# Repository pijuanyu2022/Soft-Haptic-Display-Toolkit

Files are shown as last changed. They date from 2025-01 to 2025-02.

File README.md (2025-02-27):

# Soft Haptic Display (SHD) Toolkit



A **fingertip-sized, high-resolution pneumatic haptic display** designed to provide realistic tactile feedback in virtual reality (VR) environments or during robot teleoperation. This repository includes all the **hardware** (CAD files, BOM) and **software** (Arduino, Raspberry Pi, GUI) needed to build and control the SHD.

---

## Table of Contents

- [Features](#features)
- [Screenshots](#screenshots)
- [Project Structure](#project-structure)

- [Installation](#installation)
- [Quick Start](#quick-start)
- [Documentation](#documentation)
- [Contributing](#contributing)
- [License](#license)
- [Citation & References](#citation--references)
- [Acknowledgments](#acknowledgments)

---

## Features

- **4×4 Wearable Tactile Array** – A low-cost silicone actuator array with 16 individually controlled chambers.
- **Desktop-Sized Control Box** – Integrates an Arduino Due, a Raspberry Pi, and pneumatic valves.
- **Real-Time Control** – Low-latency wireless communication between the SHD and a PC or VR platform.
- **Open-Source** – All code, CAD files, and documentation are released under the MIT license.
- **Easy to Build** – Minimal development time; accessible to students and researchers with diverse backgrounds.

---

## Screenshots

The **4 × 4 tactile array haptic display (red)** is connected to the **control box (white)** via transparent air tubes. The control box communicates with the laptop **wirelessly** using a socket communication method.

<p>
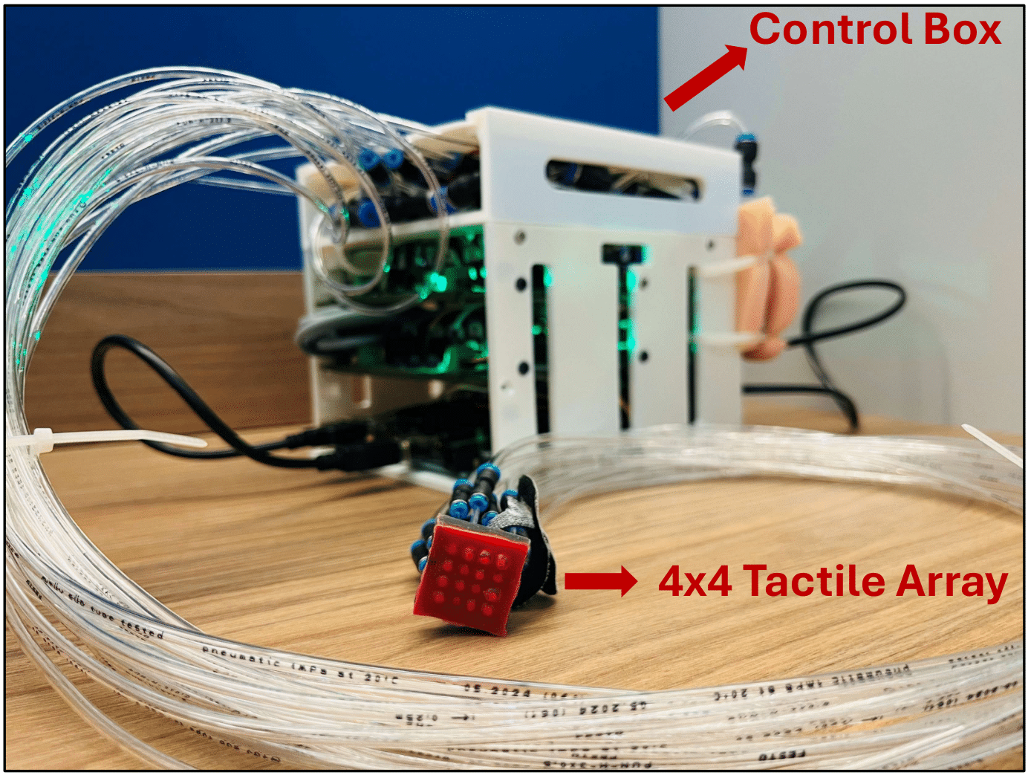
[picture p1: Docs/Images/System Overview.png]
static animation 1
  
  
</p>

**Selected Static Patterns**
<p>
  static animation 1
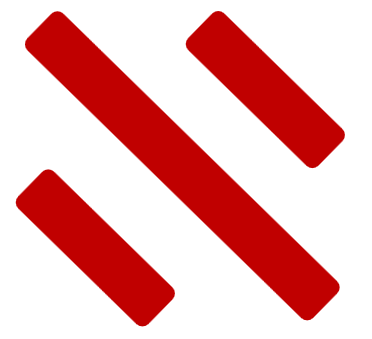
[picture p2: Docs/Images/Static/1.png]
static 1
  
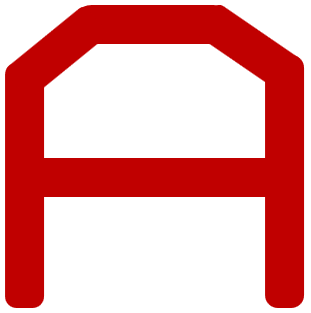
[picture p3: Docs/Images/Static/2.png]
static 2
  
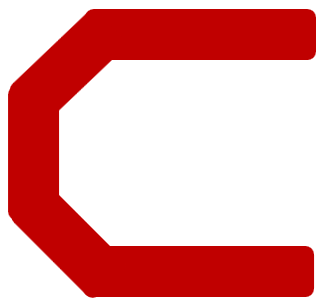
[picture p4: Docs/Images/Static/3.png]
static 3
  
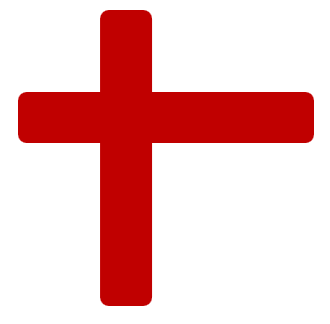
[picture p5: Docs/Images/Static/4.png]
static 4
  
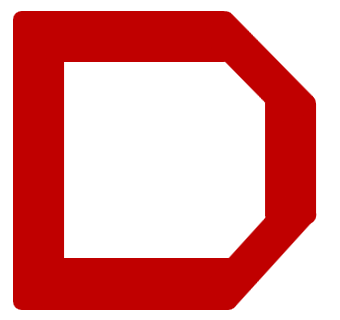
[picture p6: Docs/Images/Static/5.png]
static 5
  
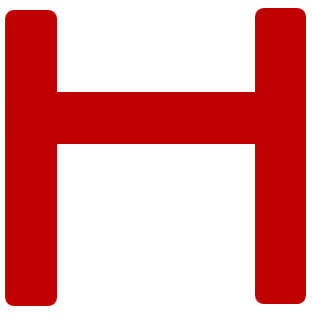
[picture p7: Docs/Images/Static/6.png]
static 6
  
  
</p>

**Selected Animation Patterns**
<p>
  Animation gif 1
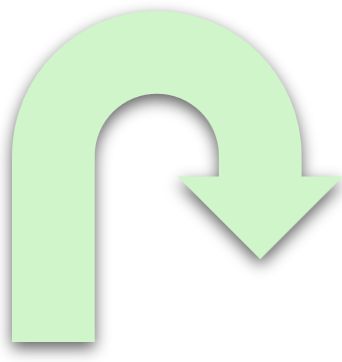
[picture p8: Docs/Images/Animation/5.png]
Animation 1
  
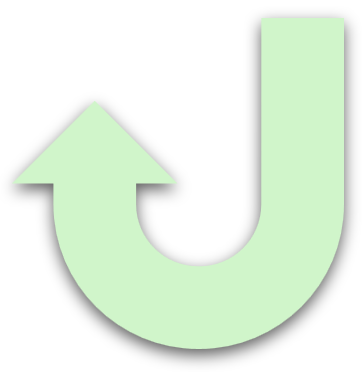
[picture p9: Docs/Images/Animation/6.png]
Animation 2
  
</p>

<p>
  Animation gif 2
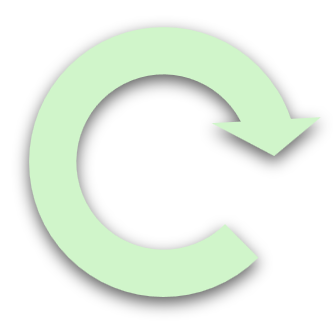
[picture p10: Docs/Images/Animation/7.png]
Animation 3
  
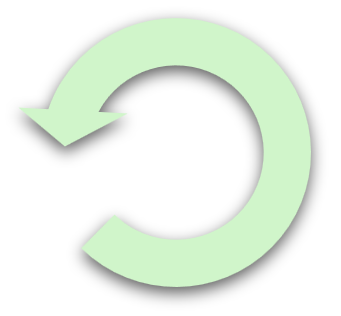
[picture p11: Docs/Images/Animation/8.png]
Animation 4
  
  
</p>

<p>
  Animation gif 3
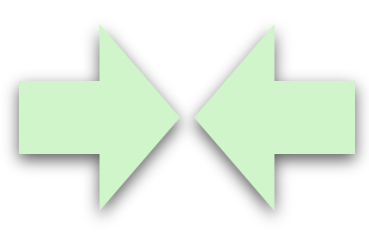
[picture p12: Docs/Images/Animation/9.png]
Animation 5
  
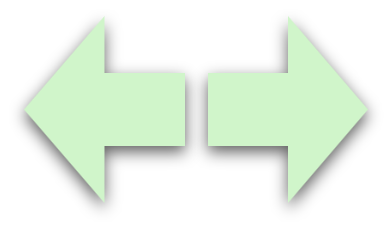
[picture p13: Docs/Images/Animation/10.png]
Animation 6
  
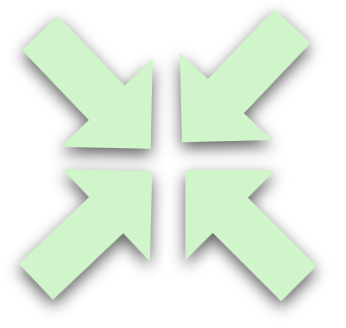
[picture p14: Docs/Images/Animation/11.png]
Animation 7
  
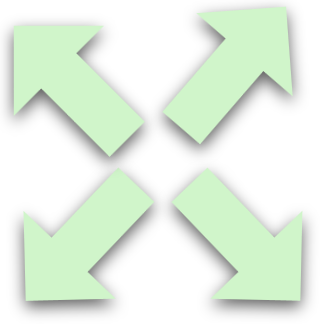
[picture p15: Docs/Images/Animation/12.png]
Animation 8
  
  
</p>

---

## Project Structure

Here’s an overview of how this repository is organized:

```plaintext
Soft-haptic-display/
├── hardware/
│   ├── CAD/           # 3D/2D design files (STLs, STEP, source CAD)
│   ├── schematics/    # Electronics circuit diagrams
│   ├── BOM/           # Bill of Materials (CSV or Markdown)
├── firmware/
│   ├── arduino/       # Arduino sketches for low-level control
│   └── raspberry_pi/  # Scripts running on the Pi
├── software/
│   └── gui/           # GUI code on the Computer for controlling the SHD
├── docs/
│   ├── manual/        # User manual, assembly guide
│   ├── images/        # Animation pictures, Gif, Static pictures
├── LICENSE
├── README.md
└── CONTRIBUTING.md

```
--- 

## Installation

### Hardware Assembly

Purchase all required items from:
- [list of Controller.md](Hardware/Bill%20of%20Materials/list%20of%20Controller.md)
- [list of Pneumatic.md](Hardware/Bill%20of%20Materials/list%20of%20Pneumatic.md)
- [list of Silicone.md](Hardware/Bill%20of%20Materials/list%20of%20Silicone.md)

Follow the instructions in [Docs/Manual/Hardware_tutorial.md](Docs/Manual/Hardware_tutorial.md) to:
1. **3D-print** the mold and control box.
2. **Fabricate** the tactile array.
3. **Solder** the control board.
4. **Assemble** the entire control box and connect it to the tactile array.

---
### Install Software on Your Windows PC

1. **Fork** this repository in GitHub.
2. **Open GitHub Desktop** and clone your fork to your local machine.
3. **Open the cloned repository** in Visual Studio Code or any other Python IDE.
4. **Locate** the `main.py` file in the `soft-haptic-display-toolkit/Software` directory:
   ```plaintext
   python main.py
   ```
5. Install all required Python libraries until the GUI successfully appears on your computer.

---
### Install Software on the Raspberry Pi

1. **Connect** the Raspberry Pi to a monitor.
2. **Open a terminal** on the Raspberry Pi:
```plaintext
git clone https://github.com/pijuanyu2022/Soft-Haptic-Display-Toolkit.git
cd Soft-Haptic-Display-Toolkit/Firmware/Raspberry_Pi/
```
3. **Create a virtual environment** in the terminal window:
```plaintext
python -m venv SoftRobo
source SoftRobo/bin/activate
```

4. **Install**  all required Python libraries so that `run_robot.py` can be opened correctly:
```plaintext
python run_robot.py
```

---
### Install Software on the Arduino Uno

1. **Connect** the Arduino Uno to your PC.
2. **Navigate** to the `/Firmware/Arduino/` directory and open `Pneumatic.ino` in the Arduino IDE.
3. **Select** Arduino Uno under *Tools → Board* in the Arduino IDE.
4. **Upload** the code to the Arduino Uno.

Tips: You can also install the Arduino IDE on the Raspberry Pi and use the Pi to upload the code to the Arduino Uno.

---
## Quick Start

#### Step 1. **Connect your PC and Raspberry Pi** to the same Wi-Fi network.

#### Step 2. **Find the Raspberry Pi’s IP address**:
- On the Raspberry Pi’s **Terminal**, type:
```plaintext
ifconfig
```
- Look for the `wlan0` or `eth0` section. The IP might look like `192.168.x.x`.

#### Step 3. **Open a Command Prompt** on your Windows PC:
- Press the **Start Menu** or **Taskbar** search, type `"cmd"`, and press Enter.

#### Step 4. Click Command Prompt and put
```plaintext
ssh [username]@[IP address]
```
- Example
```plaintext
ssh pi@192.168.1.100
```
- Enter the Pi’s password when prompted.

#### Step 5. Once connected, you should see something like:
```plaintext
pi@raspberrypi: ~ $
```
This indicates that the Command Prompt is now logged into your Raspberry Pi.

#### Step 6. Start the control script on the Pi:
```plaintext
cd Soft-Haptic-Display-Toolkit/Firmware/Raspberry_Pi/
source SoftRobo/bin/activate
python run_robot.py
```
- Keep this Command Prompt session open so the script keeps running.

#### Step 7. On your Windows PC, open Visual Studio Code (or another Python IDE):
- Navigate to the cloned repository folder:
```plaintext
Soft-Haptic-Display-Toolkit/Software
```
- Locate and **run** `main.py`.

#### Step 8. In the GUI that appears, **click the `Connect` button** (top-left corner) and **enter the Raspberry Pi’s IP address** (the same one used for SSH).

#### Step 9. **Follow** the [GUI_tutorial.md](Docs/Manual/GUI_tutorial.md) for detailed steps on controlling the tactile display.
- You should now be able to **inflate** and **deflate** the soft haptic array channels in real time!

---
## Documentation
- Assembly & Fabrication: [docs/manual/Hardware_tutorial.md](Docs/Manual/Hardware_tutorial.md)
- Firmware Guides: [docs/manual/Firmware_tutorial.md](Docs/Manual/Firmware_tutorial.md)
- GUI Usage: [docs/manual/GUI_tutorial.md](Docs/Manual/GUI_tutorial.md)
- Troubleshooting: [docs/Troubleshooting.md](Docs/troubleshooting.md)
- Bill of controller: [Hardware/Bill of Materials/list of Controller.md](Hardware/Bill%20of%20Materials/list%20of%20Controller.md)
- Bill of pneumatic system: [Hardware/Bill of Materials/list of Pneumatic.md](Hardware/Bill%20of%20Materials/list%20of%20Pneumatic.md)
- Bill of tactile dislay: [Hardware/Bill of Materials/list of Silicone.md](Hardware/Bill%20of%20Materials/list%20of%20Silicone.md)

For any **unresolved issues**, please file a ticket under the Issues tab.

---
## Contributing
We welcome all forms of contributions—bug reports, feature requests, code improvements, and documentation updates. To get started:
1. **Fork** this repository.
2. **Create** a new branch (e.g., feature/new-valve-driver).
3. **Commit** and **push** your changes.
4. **Open** a Pull Request describing your modifications.

---
## License
This project is licensed under the terms of the [MIT License](./LICENSE).

You are free to **use, modify, and distribute** this work as long as you include the original license and attribution to the authors.

---
## Citation & References
We are planning to submit this research to the 2025 Ubiquitous Robots Conference as a regular paper. The citation will be listed in the future.

---
## Acknowledgments
Special thanks to our collaborators and the open-source community:
- Our [Friesen Haptics Lab](https://www.friesenhaptics.com/.).
- The [INVENT Lab](https://www.theinventlab.com/).
- The [Human Factors & Cognitive Systems (HF&CS) Lab](https://tamuhfeschapter.wordpress.com/labs/human-factors-cognitive-systems-hfcs-lab/).
- The [Soft Robotics Toolkit](https://softroboticstoolkit.com/) for inspiration and design references.
- The [Soft Robotics Control-unit (SRC)](https://github.com/chukhanhhoang/SoftRoboticSetupFesto?tab=readme-ov-file) for control references.

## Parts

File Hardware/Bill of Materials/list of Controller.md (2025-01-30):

| **Item** | **Description** | **Quantity** | **Supplier** | **Part Number** | **Approx. Cost (USD)** |
|---|---|---:|---|---|---:|
| Raspberry Pi 5 | SBC 2.4GHZ 4 CORE 8GB RAM | 1 | Digikey | [2648-SC1112-ND](https://www.digikey.com/en/products/detail/raspberry-pi/SC1112/21658257?src=raspberrypi) | $ 80 
| Arduino Uno REV3 | Microcontroller | 1 | Arduino | [Link to Amazon](https://www.amazon.com/dp/B008GRTSV6?ref=fed_asin_title&th=1) | $ 23.50
| ACTIVE COOLER | Cooler for Raspberry Pi 5 | 1 | Digikey | [2648-SC1148-ND](https://www.digikey.com/en/products/detail/raspberry-pi/SC1148/21658255) | $ 5.00
| Pressure Regulator | 3-way proportional pressure control valve | 1 | Festo | [2171-VEAB-L-26-D13-Q4-V1-1R1-ND](https://www.festo.com/us/en/a/8067677/?autoShowCad=true) | $ 754.08 |
| Pressure Regulator Cable | Festo pressure regulator connecting cable | 1| Festo | [NEBA-M8W4-U-2.5-N-LE4](https://www.festo.com/us/en/a/8078233/) | $ 16.73
| VEAB board | Control the pressure regulator | 1 | jclPCB| [Link to jclPCB Part](https://github.com/chukhanhhoang/SoftRoboticSetupFesto/blob/main/hardware/Hardware.md)  | \$ 14.20 |
| PCA9548 | 8-Channel STEMMA QT / Qwiic I2C Multiplexer | 1 | Adafruit | [5626](https://www.adafruit.com/product/5626) | $ 5.00
| Pressure sensor | MPRLS Ported Pressure Sensor | 8 | Adafruit | [3965](https://www.adafruit.com/product/3965) | $ 29.95 each
| Air Mini Valve | 6V Air Valve with 2-pin JST XH Connector | 16 | Adafruit | [4663](https://www.adafruit.com/product/4663) | $ 2.95 each
| Air Mini Pump | Air Pump and Vacuum DC Motor - 4.5 V and 2.5 LPM | 1| Adafruit | [4699](https://www.adafruit.com/product/4699) | $ 7.95
| TIP120 Transistors | TIP120 Power Darlington Transistors - 3 pack | 20 | Adafruit | [976](https://www.adafruit.com/product/976) | $ 2.50 each
| 1N4001 Diode | 10 pack of the classic 1N4001 power blocking diode | 2 | Adafruit | [755](https://www.adafruit.com/product/755) | $ 1.50 each
| 12 V to 6V converter | DROK 12V to 6V Step Down Converter to power valves | 1 | Amazon | [Link to amazon](https://www.amazon.com/dp/B00CGQRIFG?ref=fed_asin_title) | $ 12.96
| 12 V to 5V Type-C | DC 24V/12V to 5V USB Type-C Right Angle Step Down Converter to power Raspberry Pi | 1 | Amazon | [Link to amazon](https://www.amazon.com/dp/B0BZNSDF4S?ref=fed_asin_title&th=1) | $ 8.45
| 12 V Power Supply | Adjustable Power Supply w/ 2.1mm / 5.5mm DC - 3V to 24V at 2 Amp | 1 | Adafruit | [5130](https://www.adafruit.com/product/5130?gQT=1) | $ 17.50

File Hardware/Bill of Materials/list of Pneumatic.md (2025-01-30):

| **Item** | **Description** | **Quantity** | **Supplier** | **Part Number** | **Approx. Cost (USD)** |
|---|---|---:|---|---|---:|
| Plastic tubing (6 mm OD) | 10m Plastic Tubing pipe (OD = 6mm) | 1 | Amazon | [link to Amazon](https://www.amazon.com/Quickun-Pneumatic-Polyurethane-Compressor-Transfer/dp/B07WHJ93M6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) | \$ 12.59 |
| Plastic tubing (4 mm OD) | 30.5m PVC Tubing pipe (OD = 4mm) | 1 | Digikey | [4753-ZUSA-HT-5536-ND](https://www.digikey.com/en/products/detail/fix-supply/ZUSA-HT-5536/17787802) | \$ 26.86 
|Plastic tubing (3 mm OD) | 50 m Plastic tubing pipe (OD = 3 mm. ID = 2.1 mm) | 1 |Festo | [PUN-H-3X0,5-NT](https://www.festo.com/us/en/a/197375/) |$47.5 
|Plastic tubing (2 mm OD) | 50 m Plastic tubing pipe (OD = 2 mm. ID = 1.2 mm) | 1 |Festo | [PUN-H-2X0,4-NT](https://www.festo.com/us/en/a/197375/) |$63.5 
| 6 mm - 4 mm Connector | 6 mm to 4 mm OD Pneumatic quick Connector | 1| Amazon | [link to Amazon](https://www.amazon.com/Pneumatic-Connector-Connect-fittings-Straight/dp/B09SYZHTMR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) | $ 6.99
| 4 mm - 4 mm Connector | Push-in connector kit 4 mm to 4 mm | 3 | Amazon | [link to Amazon](https://www.amazon.com/gp/product/B08LD3YQXB/ref=ox_sc_act_title_1?smid=A37DFQ476WZ5XM&th=1) | $ 13.69 each
| 4 mm - 3 mm Connector | Push-in connector 4 mm to 3 mm | 16 | Festo | [QSM-4-3](https://www.festo.com/us/en/a/153326/) | $ 3.56 each
| 3 mm - 2 mm Connector | Push-in connector 3 mm to 2 mm | 16 | Festo | [QSM-3-2](https://www.festo.com/us/en/a/133029/) | $ 3.47 each

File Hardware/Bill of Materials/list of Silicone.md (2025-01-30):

| **Item** | **Description** | **Quantity** | **Supplier** | **Part Number** | **Approx. Cost (USD)** |
|---|---|---:|---|---|---:|
| Sil-Poxy | one component adhesive | 1 | Smooth-On | [3 ounce / Net Weight: 0.19 lbs](https://shop.smooth-on.com/sil-poxy) | $ 30.35
| Silicone Thinner | lower the mixed viscosity | 2 | Smooth-On | [Pint Unit / Net Weight: 0.9 lbs](https://shop.smooth-on.com/silicone-thinner) | $ 10.69 each
| Ecoflex 00-10  | Super-Soft, Addition Cure Silicone Rubber | 1 | Smooth-On | [Link to Amazon](https://www.amazon.com/dp/B06XPN1HVH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) | $ 33.18 
| Dragon SkinTM 10 Medium  | Addition Cure Silicone Rubber Compound | 1 | Smooth-On | [Link to Amazon](https://www.amazon.com/Smooth-Dragon-Skin-10-Medium/dp/B00NH0RHBK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) | $ 36.12 
| Model Release | Castin' Craft Mold Release & Conditioner | 1 | Michaels | [Link to Michanels](https://www.michaels.com/product/castin-craft-mold-release-conditioner-10408262) | $12.99

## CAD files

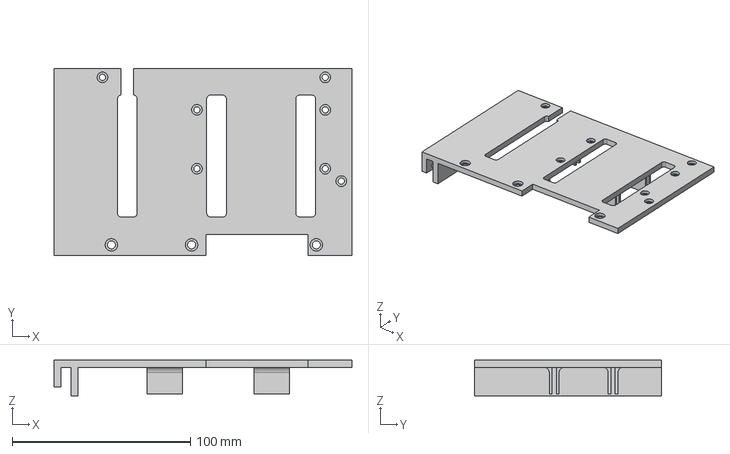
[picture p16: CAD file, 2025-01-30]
Hardware/CAD/Control Box/wall1.step
167.2 x 105.0 x 20.0 mm

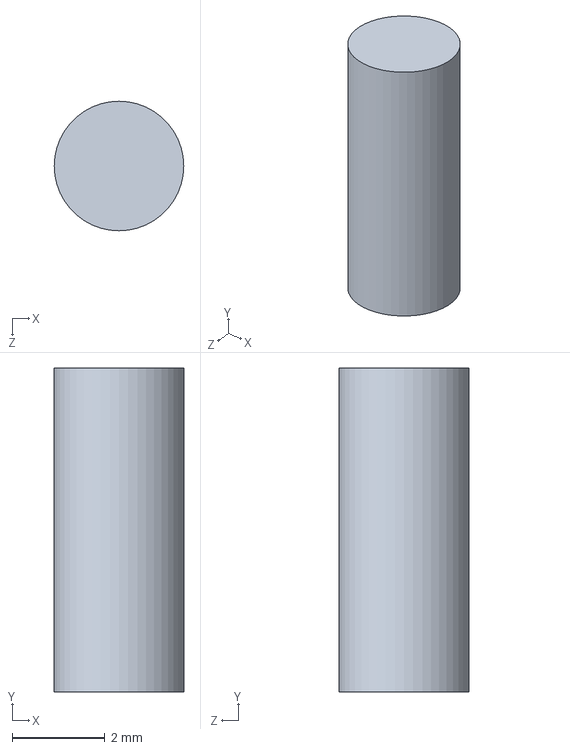
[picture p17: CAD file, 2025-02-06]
Hardware/CAD/Tactile Array Mold/4x4LowerLayerPeg_I3.SLDPRT
2.80 x 7.00 x 2.80 mm

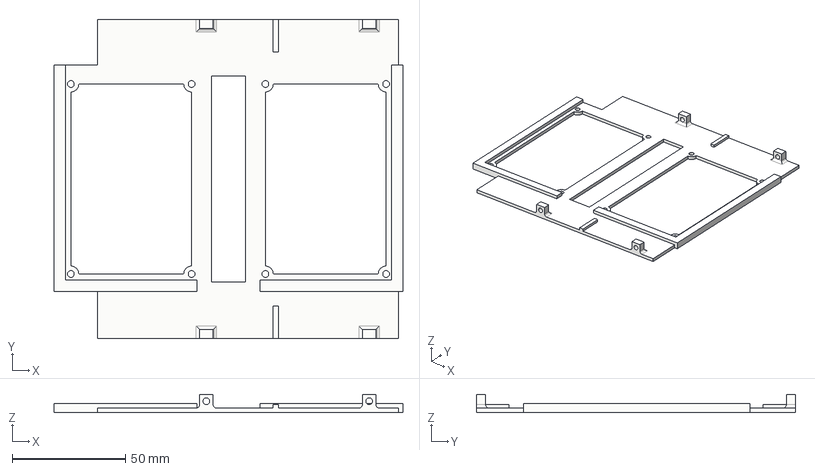
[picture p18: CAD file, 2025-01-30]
Hardware/CAD/Control Box/boardholder.step
154.3 x 141.0 x 8.00 mm

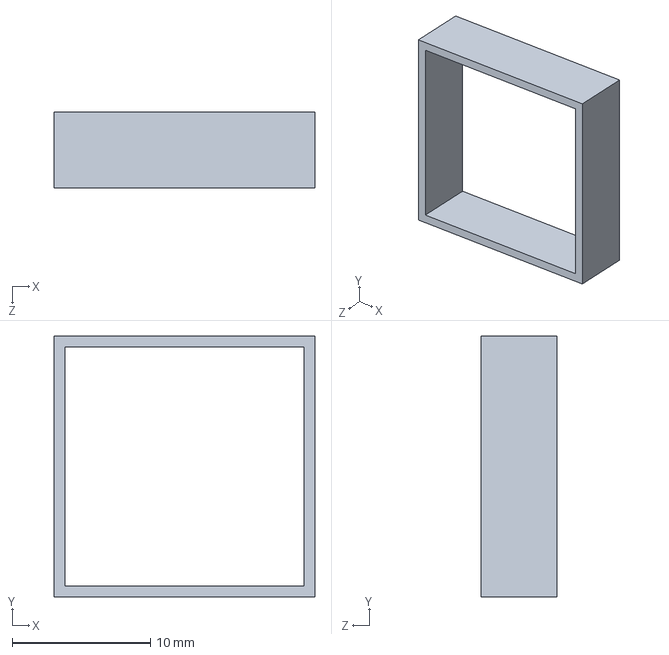
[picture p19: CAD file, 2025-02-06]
Hardware/CAD/Tactile Array Mold/4x4LowerLayerBarrier_I4.SLDPRT
18.9 x 18.9 x 5.50 mm

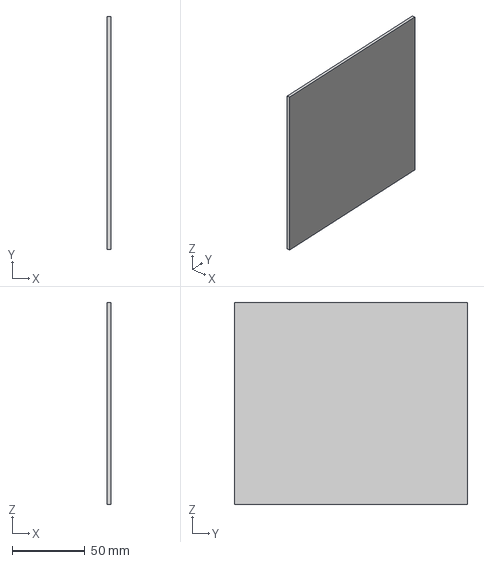
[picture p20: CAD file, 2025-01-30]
Hardware/CAD/Control Box/Top roof.step
2.50 x 160.0 x 139.0 mm

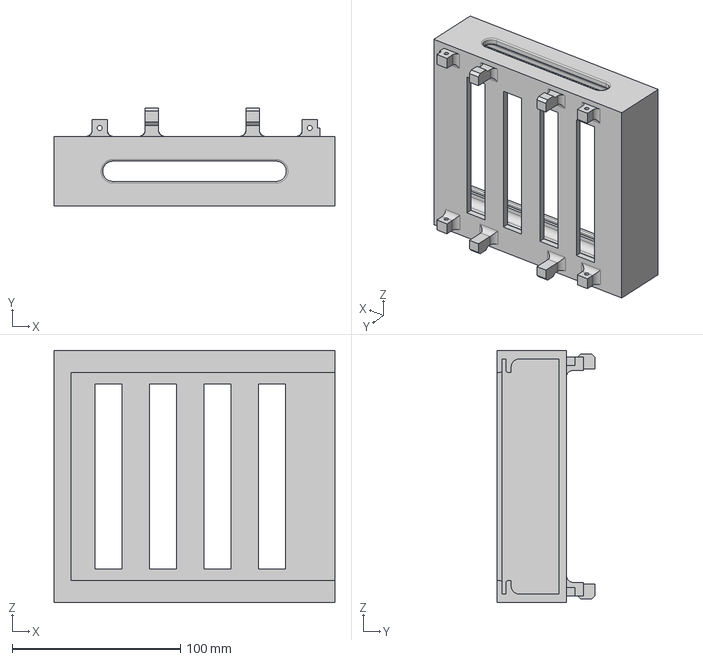
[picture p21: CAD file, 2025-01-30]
Hardware/CAD/Control Box/lid.step
167.2 x 58.5 x 150.0 mm

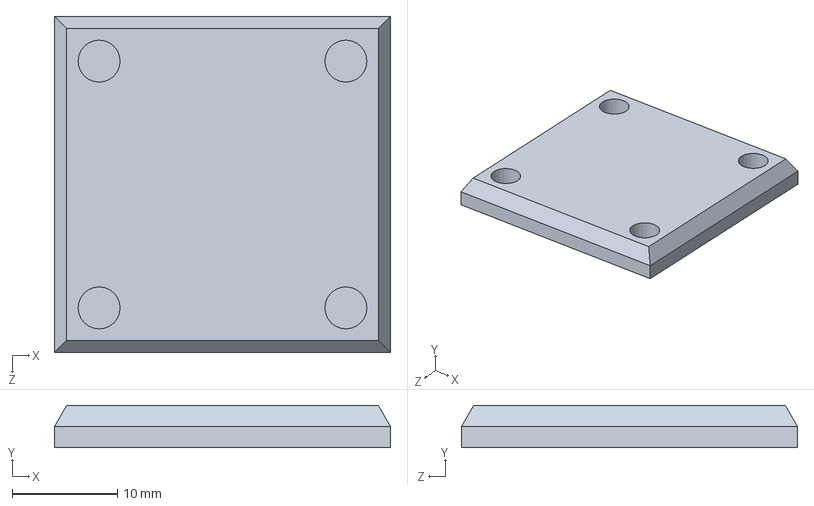
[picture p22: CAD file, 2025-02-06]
Hardware/CAD/Tactile Array Mold/4x4Lid_I11.SLDPRT
32.0 x 4.00 x 32.0 mm

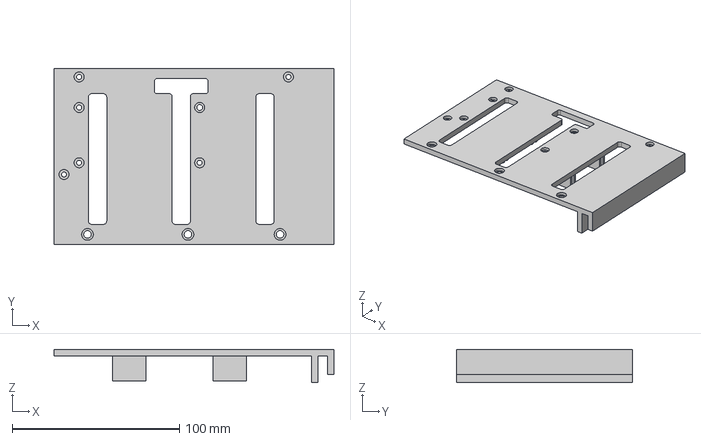
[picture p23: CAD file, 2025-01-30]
Hardware/CAD/Control Box/wall2.step
167.2 x 105.0 x 20.0 mm

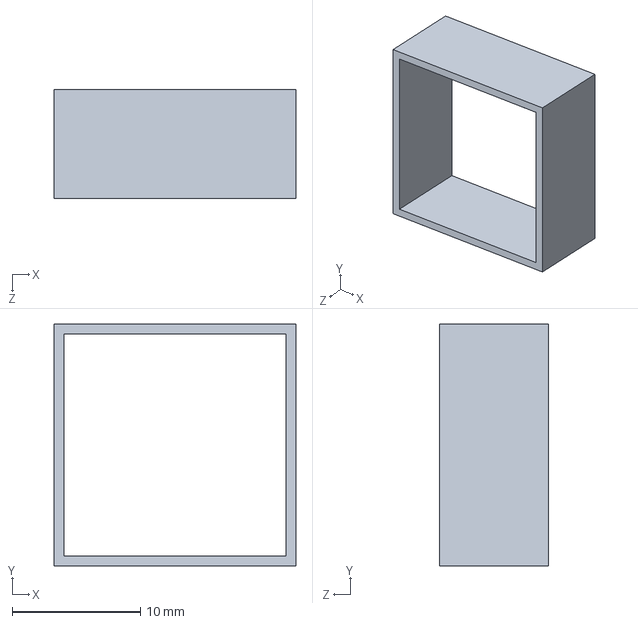
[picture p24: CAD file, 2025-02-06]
Hardware/CAD/Tactile Array Mold/4x4UpperLayerBarrier_I8.SLDPRT
18.9 x 18.9 x 8.50 mm

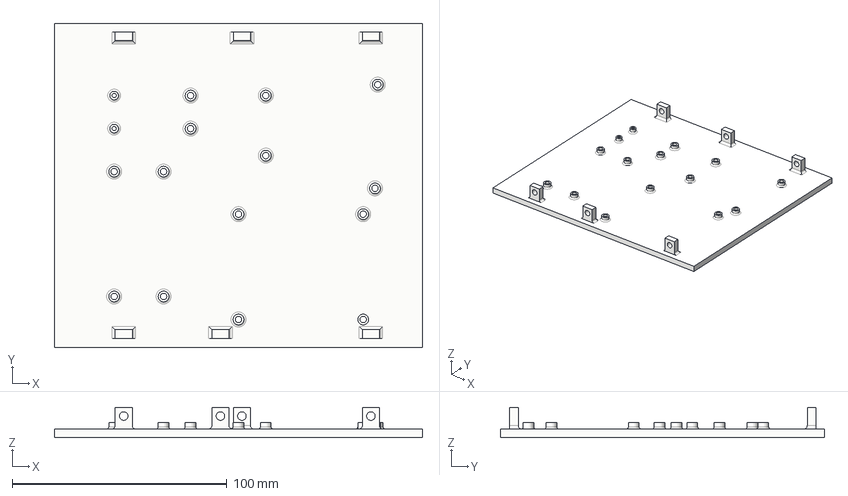
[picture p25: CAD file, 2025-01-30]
Hardware/CAD/Control Box/base.step
171.2 x 150.7 x 14.0 mm

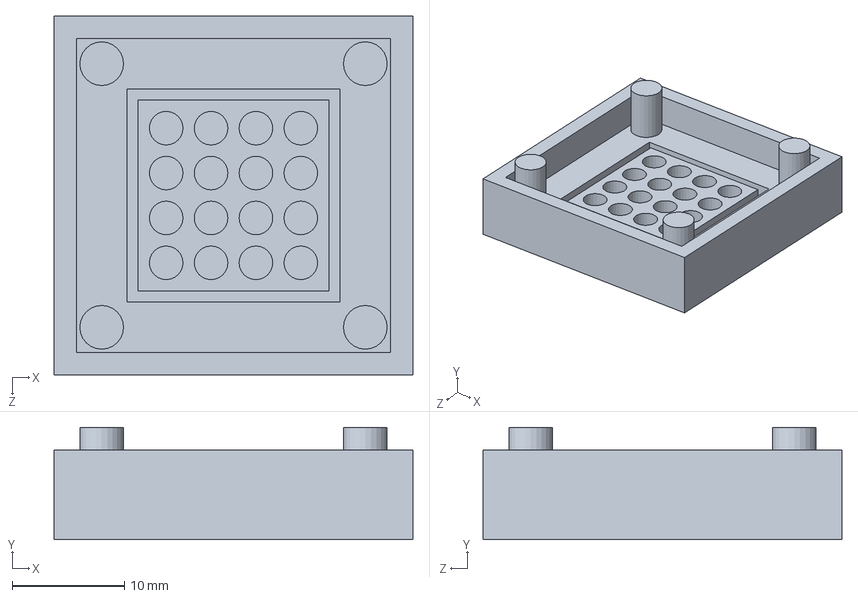
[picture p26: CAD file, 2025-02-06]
Hardware/CAD/Tactile Array Mold/4x4LowerLayerMold_I4.SLDPRT
32.0 x 10.0 x 32.0 mm

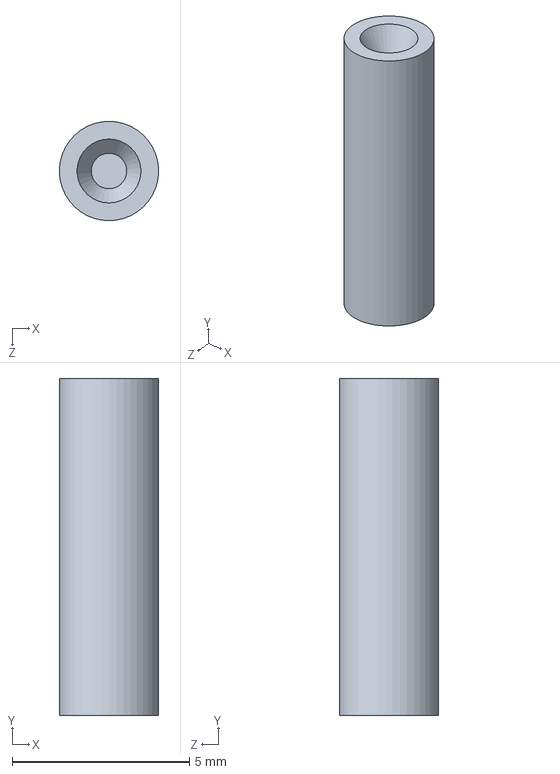
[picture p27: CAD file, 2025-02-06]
Hardware/CAD/Tactile Array Mold/4x4UpperLayerPeg_I13.SLDPRT
2.79 x 9.50 x 2.80 mm

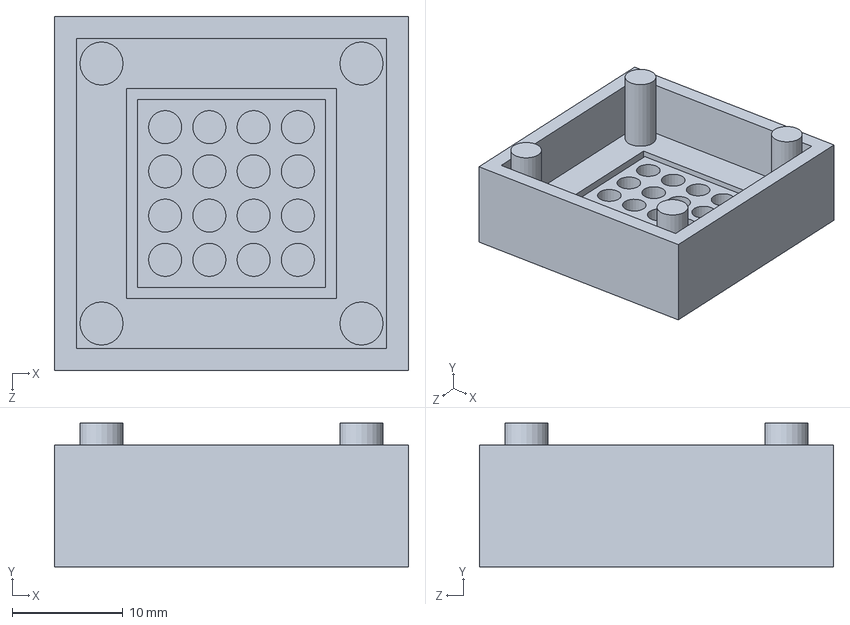
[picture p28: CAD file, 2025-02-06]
Hardware/CAD/Tactile Array Mold/4x4UpperLayerMold_I18.SLDPRT
32.0 x 13.0 x 32.0 mm

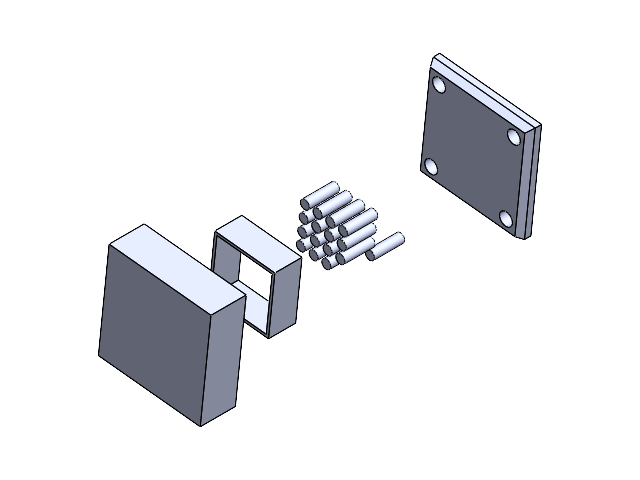
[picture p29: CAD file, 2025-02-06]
Hardware/CAD/Tactile Array Mold/UpperLayerMoldAssembly.SLDASM
4x4Barrier_I8
4x4BottomLid_I11
4x4BottomMold_I18
4x4Pin_I13 x 16

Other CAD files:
Hardware/CAD/Tactile Array Mold/LowerLayerMoldAssembly.SLDASM

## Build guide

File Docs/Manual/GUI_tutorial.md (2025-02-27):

# GUI Tutorial

This tutorial provides a step-by-step guide for setting up and using the Graphical User Interface (GUI) developed in **CustomTkinter** for controlling the high-resolution tactile array. The GUI is divided into four main panels—**Setting Panel**, **Pressure Regulator Panel**, **Display Panel**, and **Sensor Panel**—each with distinct functionalities. Follow the steps below to learn how to configure connections, fine-tune system parameters, and visualize sensor data.  

---

## Prerequisites

Before launching the GUI, ensure:

- You have a **Raspberry Pi** set up with the required IP address or hostname.  
- All **hardware connections** (power, solenoid valves, sensors, etc.) are properly assembled and verified.  
- The **required Python libraries** (including [CustomTkinter](https://github.com/TomSchimansky/CustomTkinter)) are installed on the controlling computer.  
- The **network connection** between your computer and the Raspberry Pi is functioning correctly.  

---

## Step 1: Launch the GUI

1. **Open a terminal** or **command prompt** on your controlling computer.  
2. Navigate to the directory containing the GUI code (e.g., `Soft-Haptic-Display-Toolkit/Software/`).  
3. **Run the main GUI script** (e.g., `main.py`).  

<p>
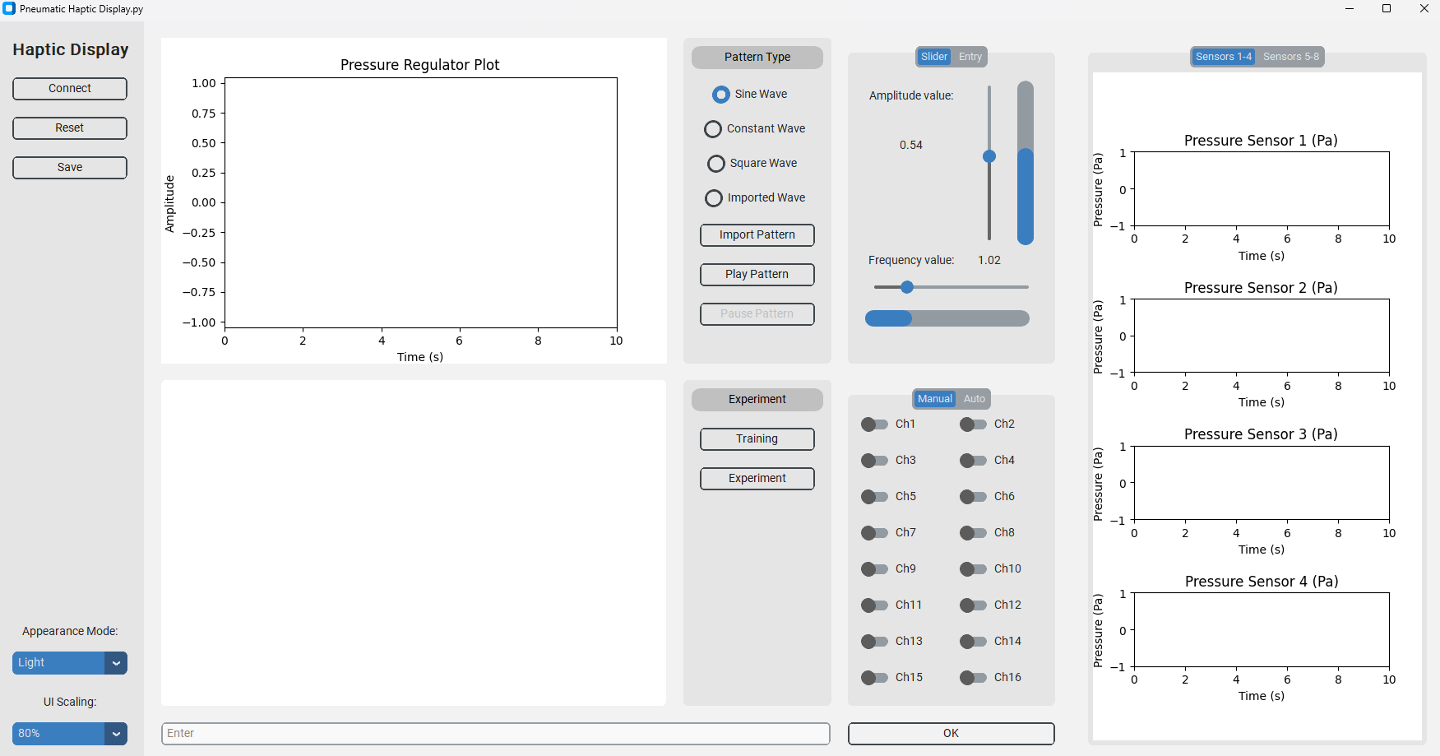
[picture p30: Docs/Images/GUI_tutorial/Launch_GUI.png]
Launch GUI
  
</p>

After a brief loading period, the main GUI window will appear.  

---

## Step 2: Configure the Setting Panel

The **Setting Panel** is your starting point for system setup, network connections, and data logging options.  

1. By default, **Setting Panel** appears in the **left** section of the GUI.
2. **Connect to the Raspberry Pi**:  
   - Click the **Connect** button.  
   - Enter the **IP address** of the Raspberry Pi in the pop-up window.  
   - Confirm the connection to establish communication.  
3. **Restore Default Settings**:  
   - If needed, click **Reset** button to reset the system to its initial configuration.  
4. **Save Data**:  
   - Enable the **Save to CSV** options if you want to **record actuator commands** and **pressure sensor data** with time stamps.  
5. **Switch Themes & Scale**:  
   - Choose **Light** or **Dark** mode.  
   - Adjust the **Scale** between **80%–120%** to suit your display.  

<p>
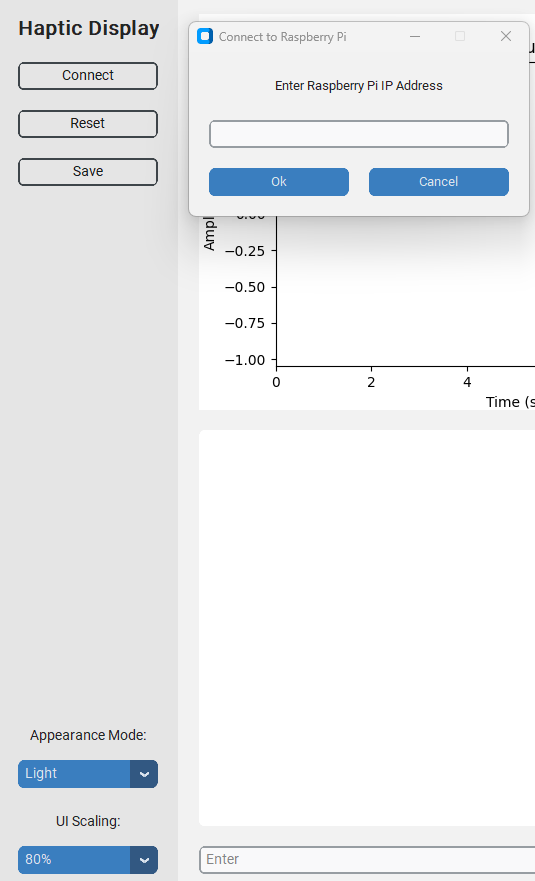
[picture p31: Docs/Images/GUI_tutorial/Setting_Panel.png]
Setting Panel
  
</p>

> **Tip**: The Setting Panel is designed for **quick adjustments** and **record-keeping**. Always confirm the Raspberry Pi connection is successful before proceeding.

---

## Step 3: Adjust Pressure in the Pressure Regulator Panel

The **Pressure Regulator Panel** allows you to **control and visualize** the internal pressure of the tactile array. It typically appears on the **top-right** or **right** side of the GUI window.

1. **Real-Time Plot**:  
   - Observe the real-time plot on the **left** side, which shows the **normalized control signal** over time. This represents how the voltage to the regulator changes dynamically.
2. **Select Waveforms**:  
   - In the **middle** section, choose from **Sinusoidal**, **Square**, **Constant**, or **Custom-Imported** waveforms to control air pressure.  
   - **Constant** is useful for maintaining a **uniform pressure** for stable force output.
3. **Tune Parameters**:  
   - On the **right** side, you can adjust **amplitude** (for sinusoidal, square, and constant waveforms) and **frequency** (for sinusoidal and square waves).  
   - Use the **slider** or **direct text-entry** fields for precise control.

<p>
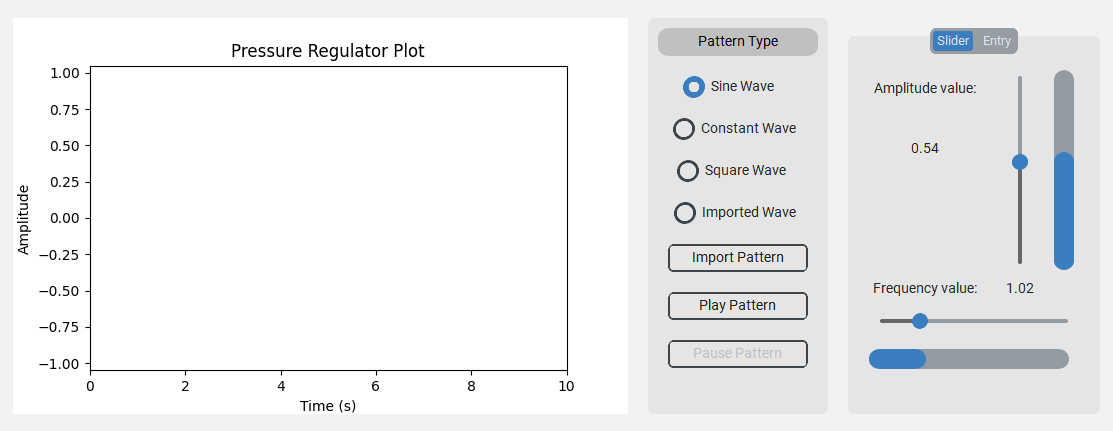
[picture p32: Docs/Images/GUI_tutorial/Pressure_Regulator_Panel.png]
Pressure Regulator Panel
  
</p>

> **Note**: If you choose a **custom waveform**, ensure that the imported file is properly formatted (e.g., CSV or text file) and that the amplitude/frequency values are within safe limits for your hardware.

---

## Step 4: Operate the Display Panel

The **Display Panel** provides **real-time feedback**, controls for **individual valves**, and an **auto-animation** feature.

1. **Log Window** (left side):  
   - Monitor **user inputs** and **system messages**. Use these logs for **troubleshooting** and **traceability**.
2. **Additional Windows** (middle section):  
   - Use the **Training** button or **Experiment** buttons to display **12 static patterns** and **12 animation patterns**.
3. **Valve Controls** (right side):  
   - There are **16 toggle buttons**, each corresponding to one of the array’s valves.  
   - Click to **activate** or **deactivate** each channel to create **custom patterns**.
4. **Auto Tab**:  
   - Access **preprogrammed animation sequences** for demonstrations or quick testing.  
5. **Help Command** (bottom):  
   - Type **help** (or click a dedicated **Help** button, if available) to display a **concise tutorial** in the log window.

<p>
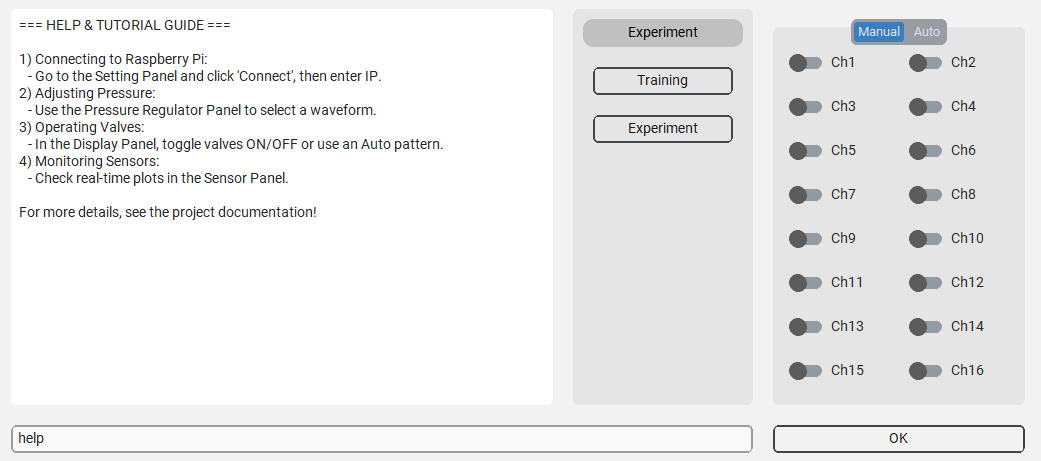
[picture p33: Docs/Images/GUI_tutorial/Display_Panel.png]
Display Panel
  
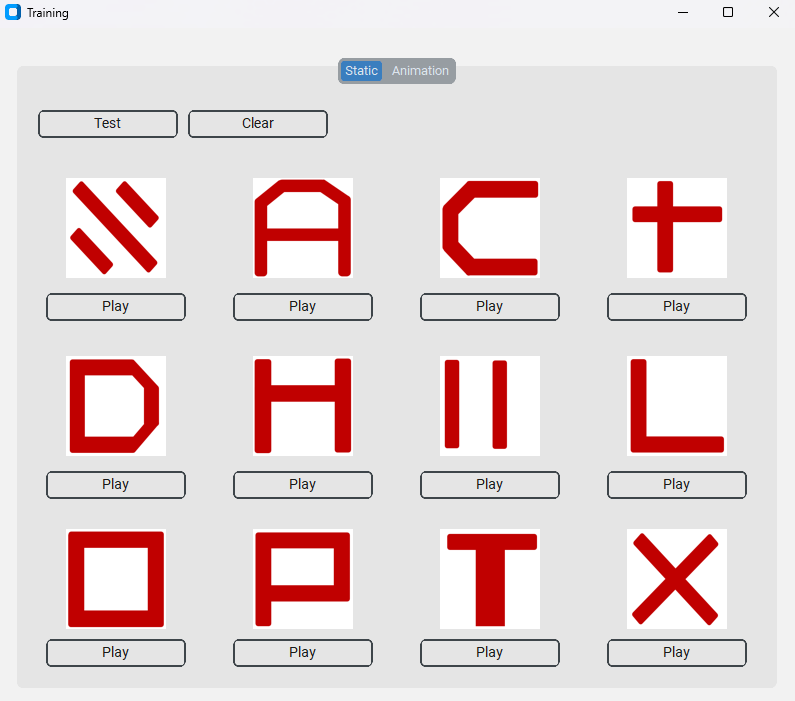
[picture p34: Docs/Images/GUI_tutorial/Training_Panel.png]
Training Panel
  
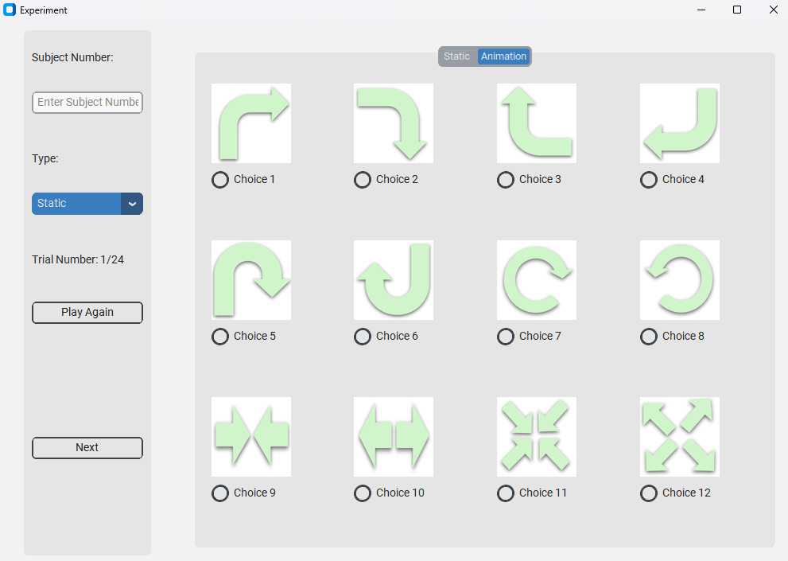
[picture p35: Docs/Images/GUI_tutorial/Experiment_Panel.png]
Experiment Panel
  
</p>

> **Tip**: Use the log window to confirm each valve’s status and quickly identify if a channel is unresponsive.

---

## Step 5: Monitor Sensors in the Sensor Panel

The **Sensor Panel** provides **live feedback** on the pressure sensor readings over time. It is essential for **diagnostics** and **performance monitoring**.

1. **Real-Time Plots**:  
   - There are **eight plots**, arranged in **two tabbed views**: Sensors **1–4** and Sensors **5–8**.  
   - Each plot shows the **pressure sensor data** in real-time, allowing you to quickly spot any irregularities.
2. **Tabs for Organization**:  
   - Click between the **tabs** to switch from **Sensors 1–4** to **Sensors 5–8**.  
   - This modular layout can be expanded if you have **more than eight sensors** in your setup.
3. **Troubleshooting**:  
   - Watch for **unexpected spikes** or **flat lines** in the sensor data.  
   - Irregularities may indicate **leaks**, **blockages**, or **pressure inconsistencies** in the system.

<p>
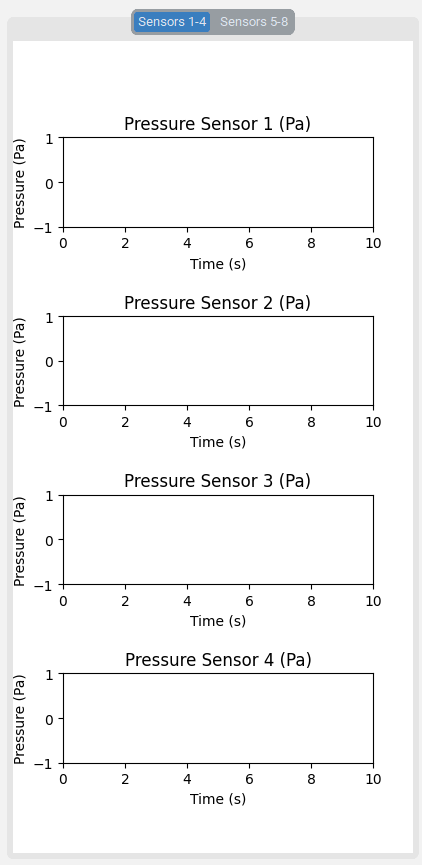
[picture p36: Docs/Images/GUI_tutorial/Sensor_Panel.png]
Sensor Panel
  
</p>

> **Note**: If the sensors are not displaying data, confirm that the **sensor connections** are secure and that the **I²C** or other communication protocols are configured correctly.

---

## Step 6: Review and Logging Best Practices

- **Verify** your pressure control and sensor readings frequently, especially when changing waveforms or switching valves.  
- **Enable CSV logging** in the Setting Panel to **record** system parameters and sensor data for **post-experiment analysis**.  
- Keep **notes** on any custom waveforms or animations you add for easier **collaboration** with other team members.

---

## Summary

With this GUI, you can:

- **Connect** to the tactile array system and **configure** its settings.  
- **Adjust** internal pressure using various waveforms.  
- **Control** individual valves or run **automated** activation sequences.  
- **Visualize** and **log** sensor data in real-time for immediate feedback and future review.

For more details on hardware and firmware configurations, refer to the other tutorials in this repository:
- [Hardware Assembly Tutorial](Hardware_tutorial.md)  
- [Firmware Tutorial](Firmware_tutorial.md)

Feel free to **customize** the GUI code to suit specific research needs or **expand** it with additional features (e.g., more sensors, advanced animations).  

---

> **Need More Help?**  
> Consult the **help** command within the GUI or contact the project maintainers for troubleshooting steps and in-depth assistance.

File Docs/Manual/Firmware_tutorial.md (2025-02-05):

# Firmware Assembly Tutorial

This tutorial provides a step-by-step guide for soldering the custom protoboard.

---

## Raspberry Pi Cable Connection

Connect the Raspberry Pi to the VEAB board using a [Qwiic I2C 4-pin cable](https://www.adafruit.com/product/4209):
- **3.3V** → Red cable 
- **GPIO 2** → Blue cable
- **GPIO 3** → Yellow cable
- **GND** → Black cable

Connect the Raspberry Pi to one protoboard through **GPIO 17, 27, 22, and 23**.

<p>
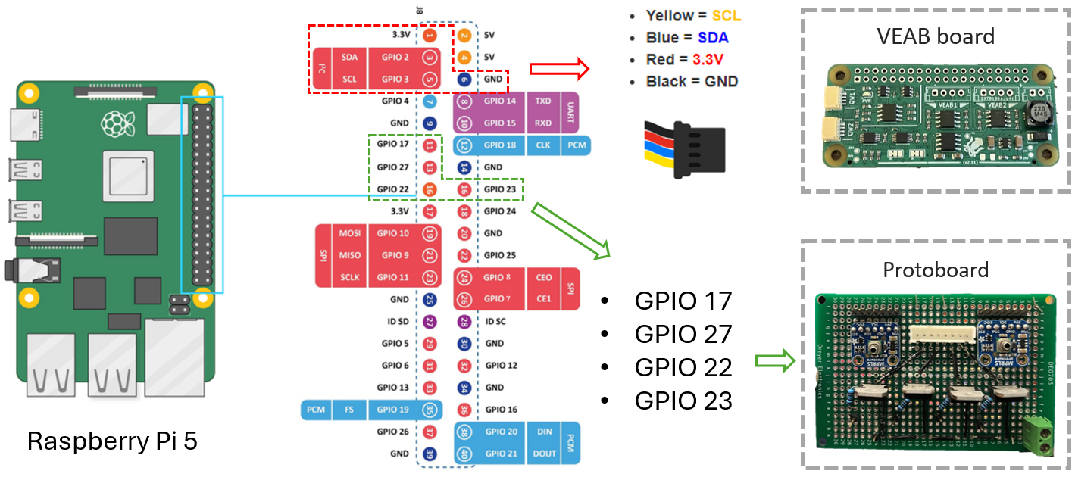
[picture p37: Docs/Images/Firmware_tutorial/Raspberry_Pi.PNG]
Raspberry Pi Connection
  
</p>

---

## Arduino Cable Connection

Connect the Arduino Uno to the PCA9548A board using a [Qwiic I2C 4-pin cable](https://www.adafruit.com/product/4209):
- **3.3V** → Red cable
- **D19** → Blue cable
- **D18** → Yellow cable
- **GND** → Black cable

Connect the PCA9548A board to four protoboards using the same type of cable for **8 pressure sensors**.

Connect the Arduino to three protoboards through **D13 to D2**.

<p>
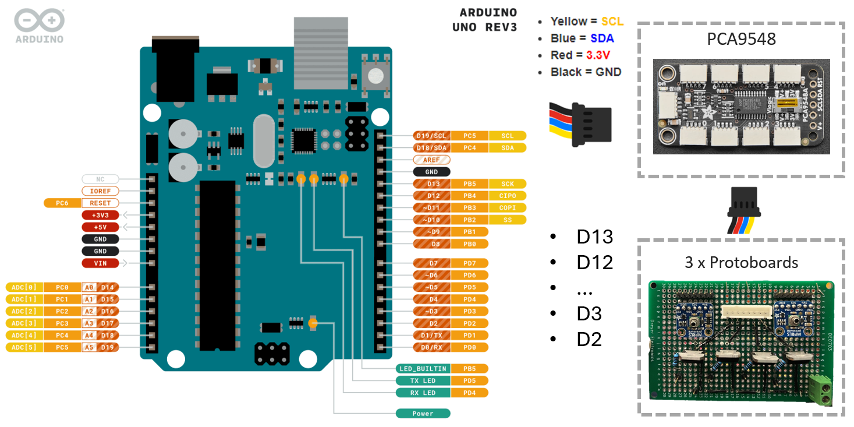
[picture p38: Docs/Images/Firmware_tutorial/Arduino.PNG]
Arduino Connection
  
</p>

---

## Front View of the Protoboard
<p>
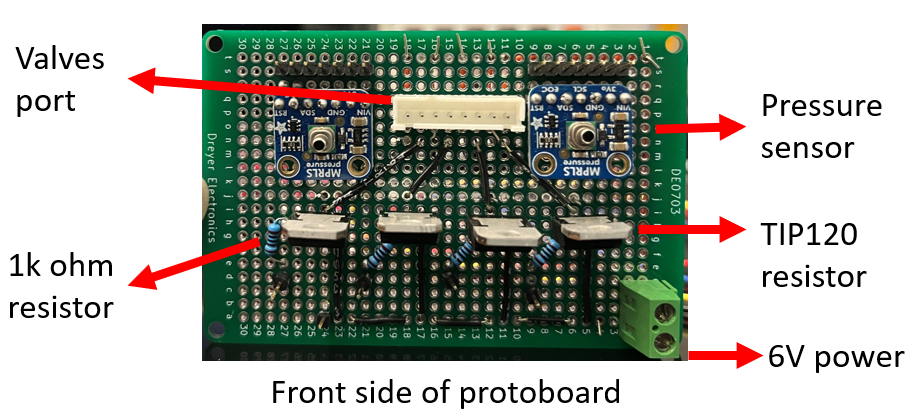
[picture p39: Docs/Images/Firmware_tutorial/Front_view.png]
Front View
  
</p>

---

## Back View of the Protoboard
<p>
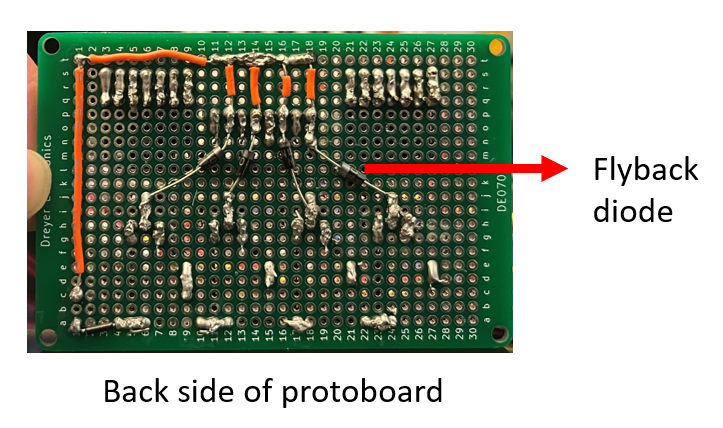
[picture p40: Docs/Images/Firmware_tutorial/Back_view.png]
Back View
  
</p>

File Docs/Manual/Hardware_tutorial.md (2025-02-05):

# Hardware Assembly Tutorial

This tutorial provides a step-by-step guide for assembling the control box. Before starting the assembly, ensure the following:

- Use a **3D printer** to print all **6** step files located in `Hardware/CAD`.
- Gather all the required components from the [List of Controller](../../Hardware/Bill%20of%20Materials/list%20of%20Controller.md).
- Prepare all **4 custom protoboards** by following the instructions in [Firmware Tutorial](Firmware_tutorial.md).

---

## Step 1: Assemble the Bottom Layer

Use a screwdriver to secure the following components to the **base 3D-printed board**:
- Raspberry Pi 5
- Arduino Uno
- 12V to 5V Type-C Converter
- 12V to 6V Converter
- VEAB Board
- PCA9548 I²C Multiplexer

<p>
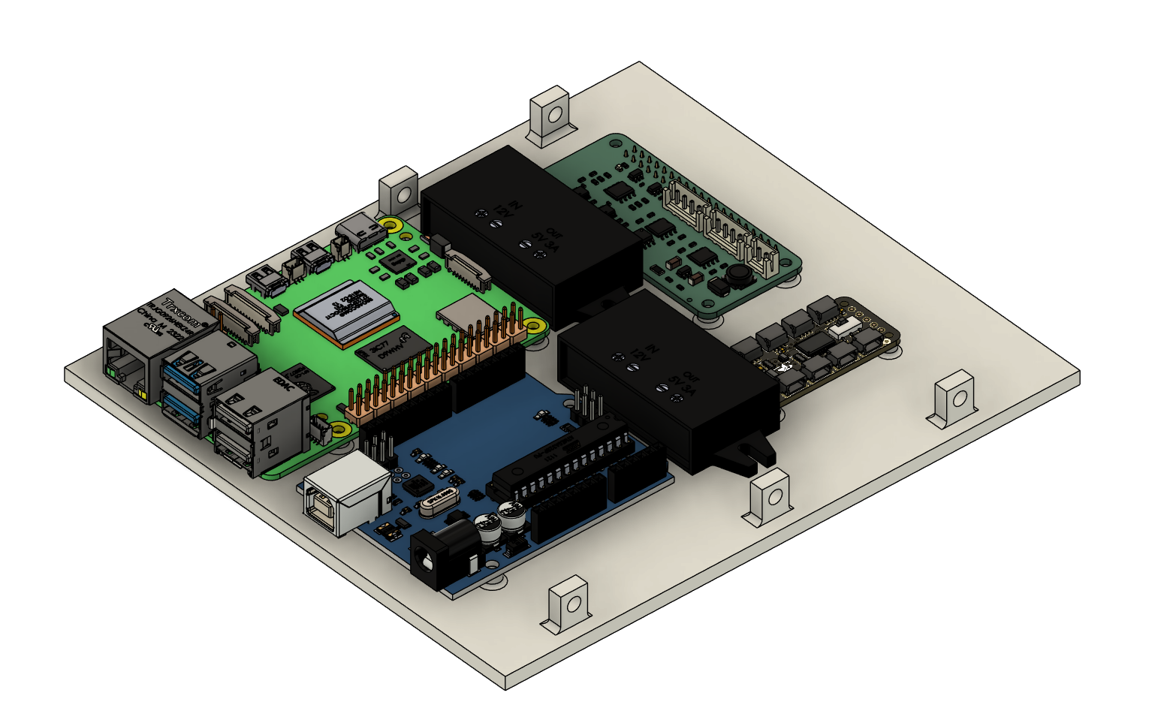
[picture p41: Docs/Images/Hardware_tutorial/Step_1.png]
Step 1
  
</p>

---

## Step 2: Assemble the Middle Layer

Attach the **3D-printed wall board** to the base board. Install the **first board holder** and place **two custom protoboards** into it.

<p>
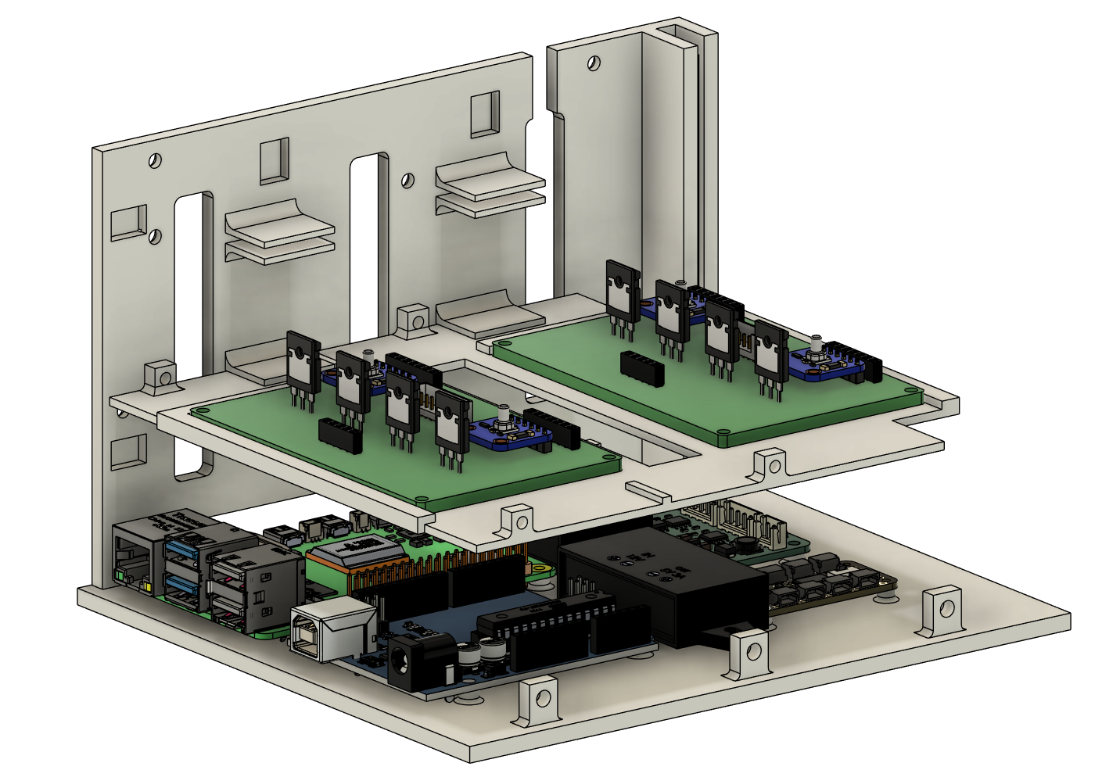
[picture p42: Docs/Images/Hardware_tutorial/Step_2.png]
Step 2
  
</p>

---

## Step 3: Continue Assembling the Middle Layer

Install the **second board holder** and insert the remaining **two custom protoboards**.

<p>
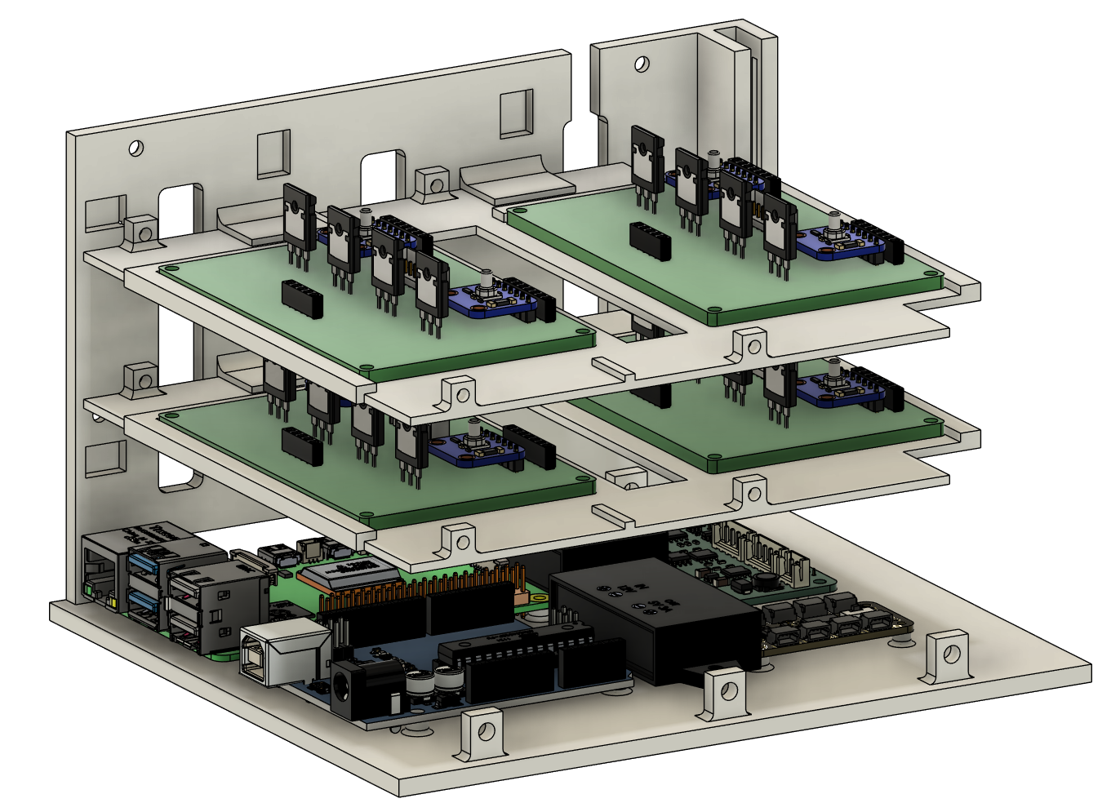
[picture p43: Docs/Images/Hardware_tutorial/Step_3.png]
Step 3
  
</p>

---

## Step 4: Assemble the Top Layer

- Insert the **power supply** at the back of the control box.
- Secure the **top roof board**.
- Use **straps** to attach the **pressure regulator** to the box.

<p>
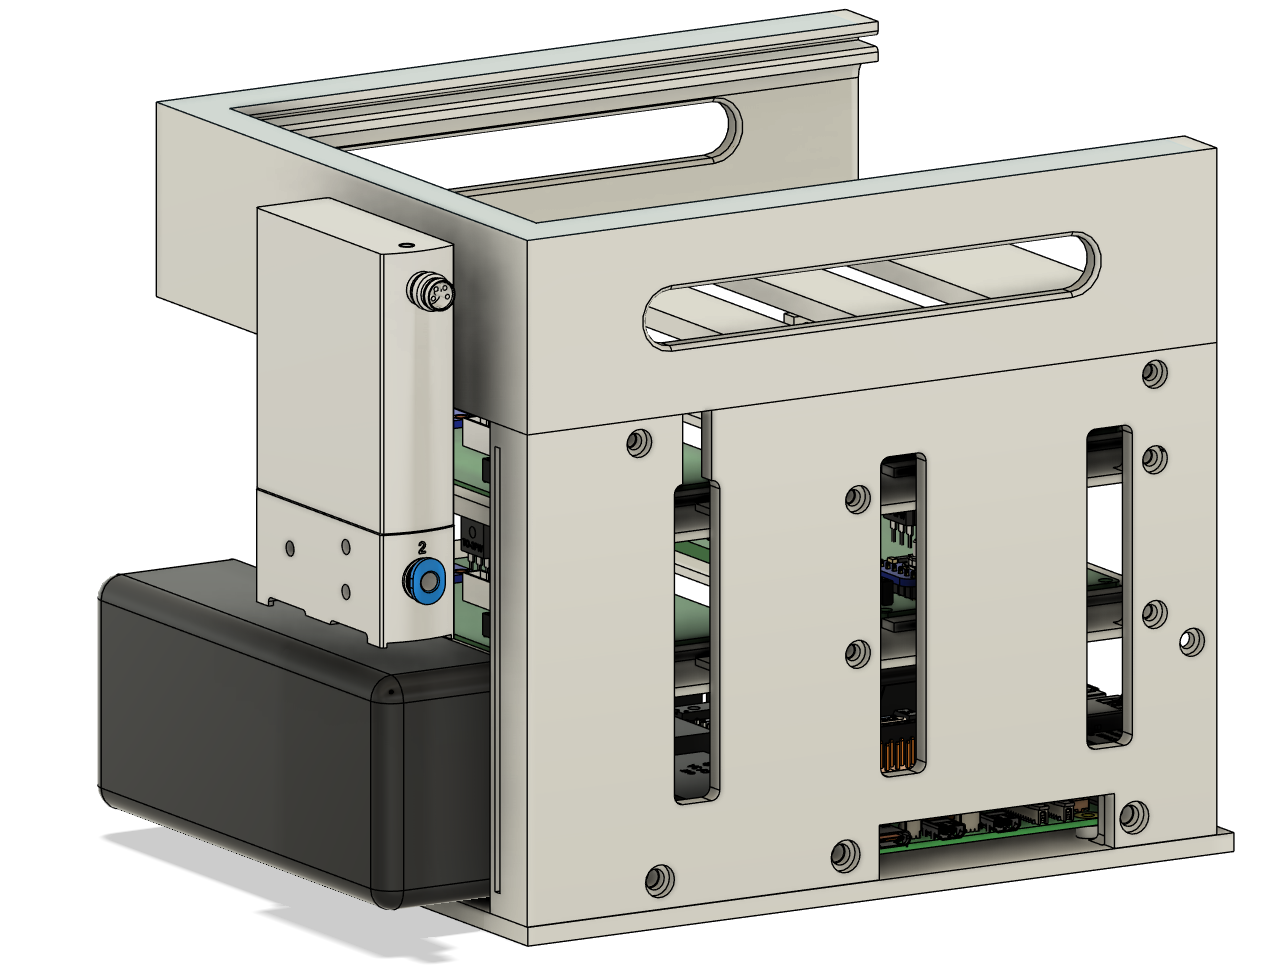
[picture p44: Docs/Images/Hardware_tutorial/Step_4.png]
Step 4
  
</p>

---

## Step 5: Assemble the Left Layer

- Attach the **other side wall board**.
- Mount all **16 solenoid valves** onto the **top roof board**.
- Use **straps** to secure the **micro pump** to the box.

<p>
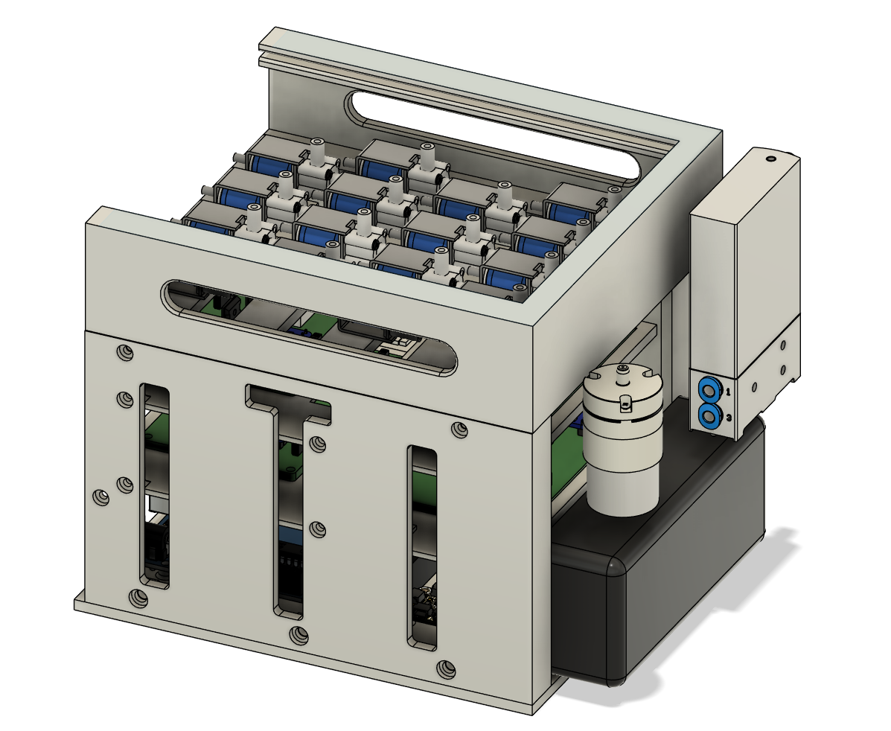
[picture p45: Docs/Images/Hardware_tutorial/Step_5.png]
Step 5
  
</p>

---

## Step 6: Attach the Lid and Finalize Assembly

Insert the **lid board** into the **top roof board** to complete the control box assembly.

<p>
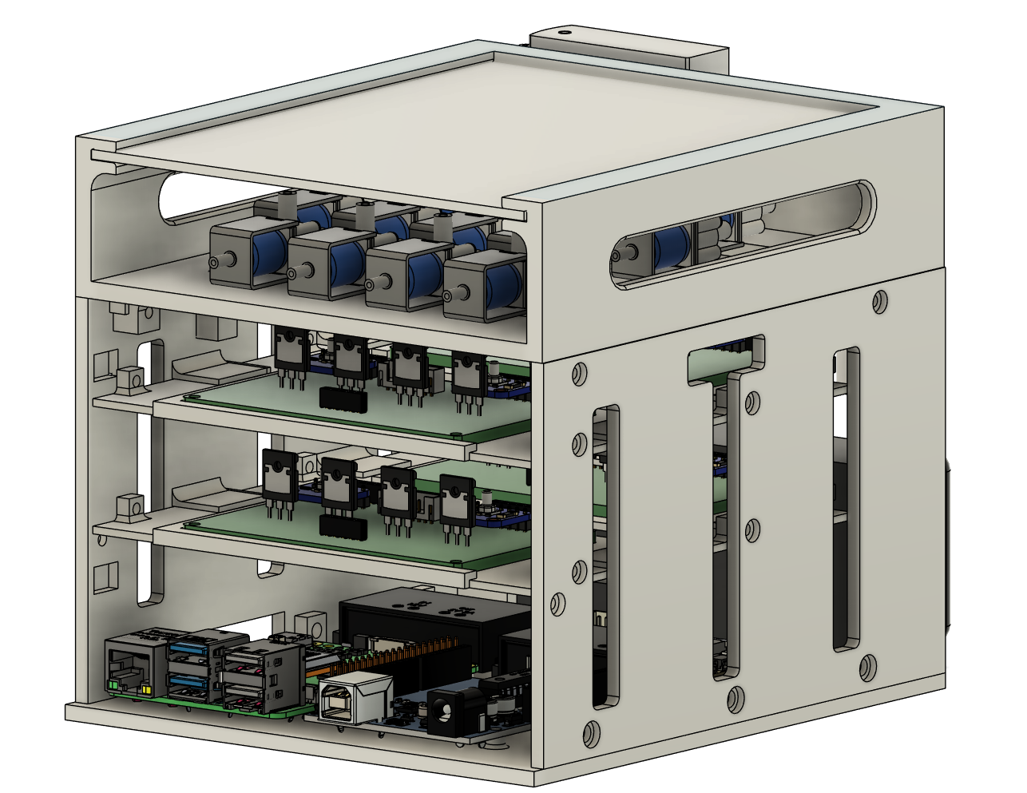
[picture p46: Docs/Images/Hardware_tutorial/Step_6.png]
Step 6
  
</p>

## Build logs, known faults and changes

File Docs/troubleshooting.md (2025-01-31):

# Trouble Shooting

**Please check the port of pressure regulator !!!!!**

- 1 is connected to the pump
- 2 is connected to the display
- 3 is connected to the exhaust air

## if get this error:

```plaintext
    C:\Users\pijuanyu>ssh pijuanyu@10.247.250.181
    @@@@@@@@@@@@@@@@@@@@@@@@@@@@@@@@@@@@@@@@@@@@@@@@@@@@@@@@@@@
    @    WARNING: REMOTE HOST IDENTIFICATION HAS CHANGED!     @
    @@@@@@@@@@@@@@@@@@@@@@@@@@@@@@@@@@@@@@@@@@@@@@@@@@@@@@@@@@@
    IT IS POSSIBLE THAT SOMEONE IS DOING SOMETHING NASTY!
    Someone could be eavesdropping on you right now (man-in-the-middle attack)!
    It is also possible that a host key has just been changed.
    The fingerprint for the ED25519 key sent by the remote host is
    SHA256:AG70F5dXTXLXOF5b2VTTpmoHVs8Ve3Xg84qNDWIqYBk.
    Please contact your system administrator.
    Add correct host key in C:\\Users\\pijuanyu/.ssh/known_hosts to get rid of this message.
    Offending ECDSA key in C:\\Users\\pijuanyu/.ssh/known_hosts:3
    Host key for 10.247.250.181 has changed and you have requested strict checking.
    Host key verification failed.
```

Type this on the windows PC:
```plaintext
    ssh-keygen -R 10.247.250.181
```

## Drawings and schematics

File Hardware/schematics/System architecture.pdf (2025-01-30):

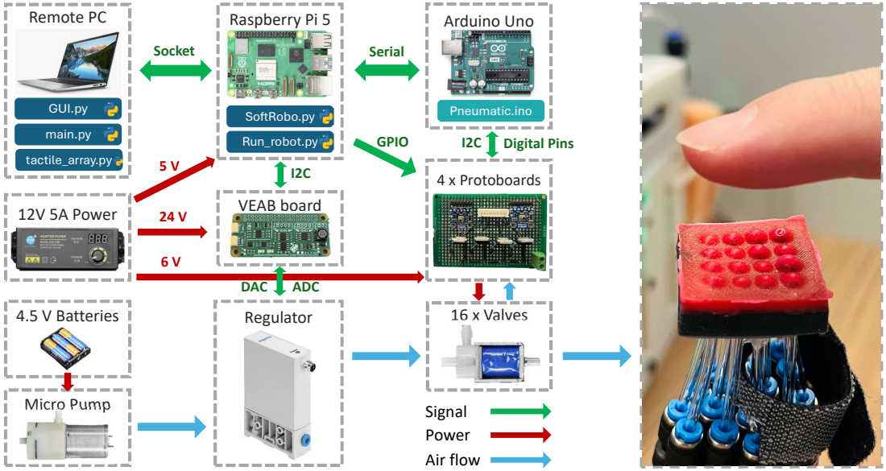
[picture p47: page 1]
Raspberry Pi 5; Run_robot.py; Arduino Uno; 12V 5A Power; VEAB board; Regulator; SoftRobo.py; Pneumatic.ino; Remote PC; GUI.py; main.py; tactile_array.py; 16 x Valves; 4 x Protoboards; Micro Pump; 4.5 V Batteries; Signal Power Air flow; Socket; Serial; DAC; ADC; GPIO; I2C Digital Pins

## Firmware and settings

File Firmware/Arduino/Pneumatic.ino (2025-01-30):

#include "Wire.h"
#include "Adafruit_MPRLS.h"

unsigned long previousTime = 0;      // Store the last time the loop executed
const unsigned long interval = 10;   // 10 ms delay

// --------------------------------------- Pressure Sensors --------------------------------------
#define PCAADDR 0x70
#define RESET_PIN  -1
#define EOC_PIN    -1

Adafruit_MPRLS mpr_sensors[8];       // Array for each sensor instance
float sensor_offsets[8];             // Calibration offsets for each sensor

unsigned long startTime;
bool calibration_complete = false;

// --------------------------------------- Actuators --------------------------------------
int solenoidPins[12] = {13, 12, 11, 10, 9, 8, 7, 6, 5, 4, 3, 2};

// PCA9548A channels: Using all 8 channels (0 to 7)
uint8_t sensor_channels[8] = {0, 1, 2, 3, 4, 5, 6, 7};

void pcaselect(uint8_t i) {
  if (i > 7) return;  // Ensure channel index is within range
  Wire.beginTransmission(PCAADDR);
  Wire.write(1 << i);
  Wire.endTransmission();  
}

void setup() {
  Serial.begin(115200);
  while (!Serial);
  delay(1000);

  Wire.begin();
  Serial.println("Starting sensor calibration...");

  startTime = millis();

  for (uint8_t t = 0; t < 8; t++) {
    pcaselect(sensor_channels[t]);
    if (!mpr_sensors[t].begin()) {
      Serial.print("Failed to find MPRLS sensor on channel ");
      Serial.println(sensor_channels[t]);
    } else {
      Serial.print("Found MPRLS sensor on channel ");
      Serial.println(sensor_channels[t]);
      sensor_offsets[t] = mpr_sensors[t].readPressure();
      Serial.print("Calibrating sensor on channel "); 
      Serial.print(sensor_channels[t]);
      Serial.print(", Offset: "); 
      Serial.println(sensor_offsets[t]);
    }
  }
  Serial.println("Calibration complete.");
  calibration_complete = true;

  for (uint8_t i = 0; i < 12; i++) {
    pinMode(solenoidPins[i], OUTPUT);
  }
}

void loop() {
  unsigned long currentTime = millis();
  if (currentTime - previousTime >= interval) {
    previousTime = currentTime;  // Update the last executed time

    // ------------------------- Actuators ------------------------------------
    if (Serial.available() > 0) {
      String input = Serial.readStringUntil('\n');
      input.trim();

      // Process binary string for valve control
      if (input.length() == 12) { // Expect a 12-bit binary string
          bool isValid = true;

          // Validate the binary string contains only '0' or '1'
          for (char c : input) {
            if (c != '0' && c != '1') {
              isValid = false;
              break;
            }
          }

          if (isValid) {
              // Update valve states based on the binary string
              for (uint8_t i = 0; i < 12; i++) {
                  bool state = (input[i] == '1');
                  digitalWrite(solenoidPins[i], state ? HIGH : LOW);
              }
              Serial.println("Updated valve states from binary string.");
          } else {
              Serial.println("Invalid binary string received.");
          }
      } else {
          Serial.println("Invalid input length received.");
      }
    }

    // ------------------- Send sensor data to Pi --------------------------------
    if (!calibration_complete) {
      return;
    }

    unsigned long loopCurrentTime = millis() - startTime;

    Serial.print(loopCurrentTime);
    Serial.print(",");

    float veab_sensor = 0.0;  // Placeholder for VEAB sensor data
    Serial.print(veab_sensor);
    Serial.print(",");

    for (uint8_t t = 0; t < 8; t++) {
      pcaselect(sensor_channels[t]);
      float pressure_hPa = mpr_sensors[t].readPressure();
      float calibrated_pressure = (pressure_hPa - sensor_offsets[t]) * 100;

      Serial.print(calibrated_pressure);
      if (t < 7) Serial.print(",");
    }

    Serial.println();
  }
}

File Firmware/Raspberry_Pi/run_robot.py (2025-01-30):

from SoftRobo import SoftRobot
import numpy as np

def main():
    # You can directly specify the I2C channels and port here
    i2c = [1]  # Example: use I2C channel 1 (you can modify this as needed)
    port = 12345  # Example: use port 12345 (you can modify this as needed)

    print('Using I2C channels: ', i2c)
    print('Using port:', port)

    # Initialize the SoftRobot object
    robot = SoftRobot(i2c=i2c, port=port)
    print(robot.nSensors, " sensor(s) initialized")

    # Wait for client connection
    robot.waitForClient()

    # Create and run all necessary processes
    robot.createProcesses()
    robot.run()

    # Wait for processes to finish
    robot.waitForProcesses()

    # Close TCP socket
    robot.socket_TCP.close()

if __name__ == "__main__":
    main()

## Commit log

2025-01-30 update all current documents
    [Top roof.step, base.step, boardholder.step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]
2025-01-30 update the bill of materials
2025-02-07 move the cad file
    [4x4Lid_I11.SLDPRT, 4x4LowerLayerBarrier_I4.SLDPRT, 4x4LowerLayerMold_I4.SLDPRT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]

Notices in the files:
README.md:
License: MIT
